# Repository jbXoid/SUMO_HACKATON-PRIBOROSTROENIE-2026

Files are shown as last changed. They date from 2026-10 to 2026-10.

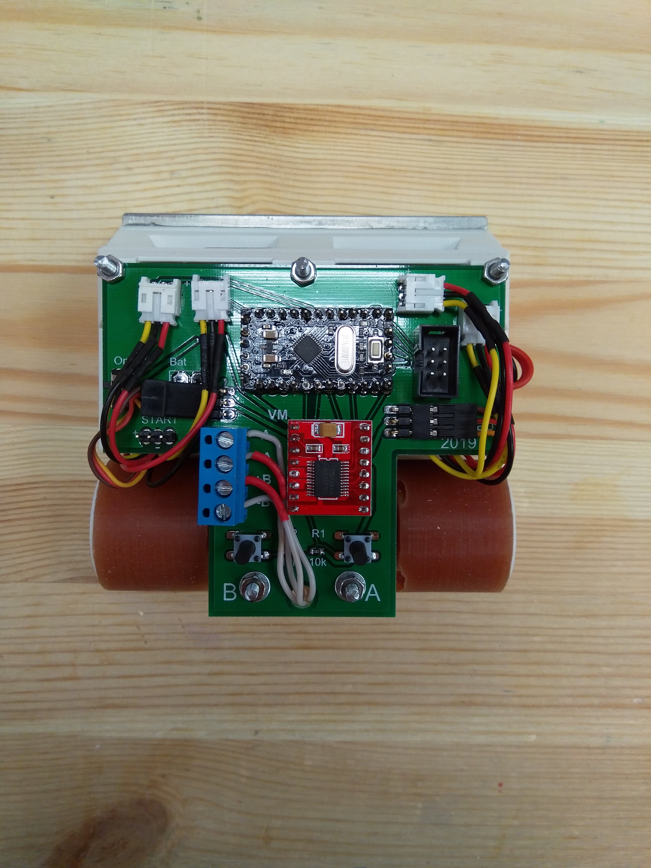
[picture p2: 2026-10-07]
hackaton_files/PHOTO_20191210_112957.jpg

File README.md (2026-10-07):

# Sumo_mini
Programs for ROBOTS Sumo mini

Что доделать:
1. Режим старта Start_Fast;
2. Режим "Периметр";
3. Дефайны выбора ринга (черный или белый);
4. Проработать режим ухода от атаки в бок. Подобрать настройки
5. В процессе ТОРНАДО, если происходит обнаружение цели и переход в АТАКУ, проходит слишком много времени и робот
	успевает проскачить цель. В режиме АТАКА происходит переключение в режим доворота к цели или резкого разворота.
	РЕШЕНИЕ:
	- Попробовать делать переход из "ТОРНАДО" (при обнаружении цели двумя передними датчиками) сразу в "ДОВОРОТ К ЦЕЛИ"
6. Подобрать новые параметры дальности цели в связи с найденной ошибкой поиска среднего арифметического
7. Продумать вопрос работы АЦП через прерывания

Наблюдения:
- Интересный эффект при скоростном старте робота FK35. Если размещать
	неподвижную цель слева или справа от линии входа в ринг, робот
	после входа по прямой развернётся в соответствующую сторону к
	цели.
  Это происходит случайным образом. Проходя мимо цели, в переменной
  ADCH_n сохраняется значение АЦП в момент прохода мимо цели и не
  успевает обновиться новым значением прежде чем выйдет время
  T_START_FAST_IGNORE
	
Улучшения 22.11.2020
---------------------------------------------------------------------
1. Исправлена ошибка настроийки направления вращения моторов. 
	Добавлена строка сброса "PORTD &= ~(1<<IN2|1<<IN3|1<<IN4);"
	в FSM_Go в каждом CASE.
2. Реализован алгоритм определения фронтального контакта
	"ковш в ковш". Добавлен CASE 7 атаки в режиме максимальной
	мощности.
	CASE 1 теперть называется "Выход на цель".
	else if (ADCH_R>=K_FRONT_DIST) //Цель на ковше, но смещена ВПРАВО
				{
				//Подсчёт длительности фронтального контакта.
				Start_GTimer (RRLL_Timer); 
				if(Get_GTimer(RRLL_Timer)>T_FRONT_CONTACT)
					{
					fsm_Go_state=7;
					Stop_GTimer(Motion_Timer);
					Stop_GTimer(RRLL_Timer);
					LED_ON;
					}
3. Исправлен алгоритм в "левом/правом довороте". При потере цели
	сразу переход в режим "Резкий разворот" соответственно текущему
	направлению вращения.
	В режиме "Резкий разворот" удалён кейс отсутствия цели и перехода
	в "Торнадо"
	
Ошибка поиска среднего арифметического
---------------------------------------------------------------------
- Сумма из 5 элементов делилась поразрядным сдвигом вправо на 2.
	Ошибка в том, что так можно делить только на степень двойки.
	Ср.арифм. 8ми элементов нужно сдвинуть на 3 вправо.
- Вместо макс. знач. 153 -> (153*5)>>2, получалось 191

24.07.2021
Среднее арифметическое
---------------------------------------------------------------------
- Данные АЦП сохраняются в массив Buff
- Сохраняется 8 значений каждую мс, затем суммируются
- Поразрядным сдвигом вправо на 3 делается деление на 8
-> Т.к. приходится переключать вход АЦП для каждого канала, нет
	непрерывного потока данных. В таком случае не получится вычислять
	простое скользящее среднее (SMA).
	
25.07.2021
Отключил среднее арифметическое 8ми значений АЦП
---------------------------------------------------------------------
- Значительно улучшилась скорость реакции робота
- Каких-либо импульсов данных АЦП не наблюдается

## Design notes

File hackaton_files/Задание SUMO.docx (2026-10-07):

# SUMO MINI 10X10

Команда, вам предстоит спроектировать боевого робота сумо. Сейчас тут будут накиданы все вводные)

Технические требования к роботу:

- Масса не более - 500 г
- Габаритные размеры в горизонтальной плоскости - (10 х 10) см max
- Вертикальный размер не ограничен
- Робот не должен физически разделяться на части и должен оставаться единым целым
- Робот должен быть полностью автономным
- Шины и другие компоненты робота, контактирующие с рингом, не должны быть способны поднять и удерживать лист A4 плотностью 80 г/м2 более, чем 2 секунды
- Робот не должен быть способным каким-либо образом повредить ринг, других роботов или нанести травмы людям

Что вы получаете на старте проекта:

- Печатную плату
- Электронные компоненты, датчики
- Моторы с редукторами, диски, шины
- Аккумуляторы 18650 3 шт.
- Документацию на ключевые компоненты и электрическую схему платы
- Готовый проект для микроконтроллера ATMega168 на языке Си
- Программатор USBasp
- Ринг
- Массогабаритный макет робота
- 3D модель робота

Что нужно сделать:

- Спаять плату управления роботом
- Собрать аккумуляторную сборку из 3х элементов 18650 подключенных последовательно. Напряжение питания робота 12В
- Скомпилировать проект для микроконтроллера ATMega168 в любой IDE (Microchip Studio или MPLAB для VSCODE)
- Прошить микроконтроллер;
- Внести улучшения в код и рассказать об этом;
- Доработать 3D модель корпуса робота для установки аккумуляторов 18650 и обеспечить достаточно плотную компоновку всех датчиков, электроники и силовой части, чтобы удовлетворить техническим требованиям
- Когда робот будет собран, нужно разместить робота на краю ринга так, чтобы колеса касались белой границы. Когда робот будет включен и инициализирован, он должен самостоятельно обнаружить массогабаритный макет и вытолкнуть его за пределы ринга. При этом робот не должен выпасть из ринга
- На защите проекта вам представиться возможность сразиться с роботом победителем соревнований РОБОФИНИСТ

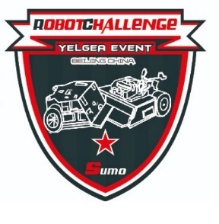
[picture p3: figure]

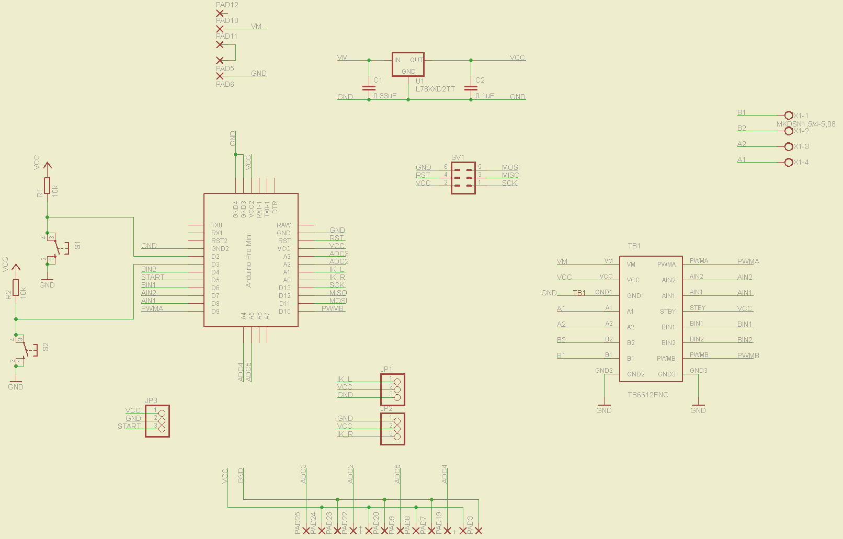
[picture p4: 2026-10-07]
hackaton_files/schematic.png

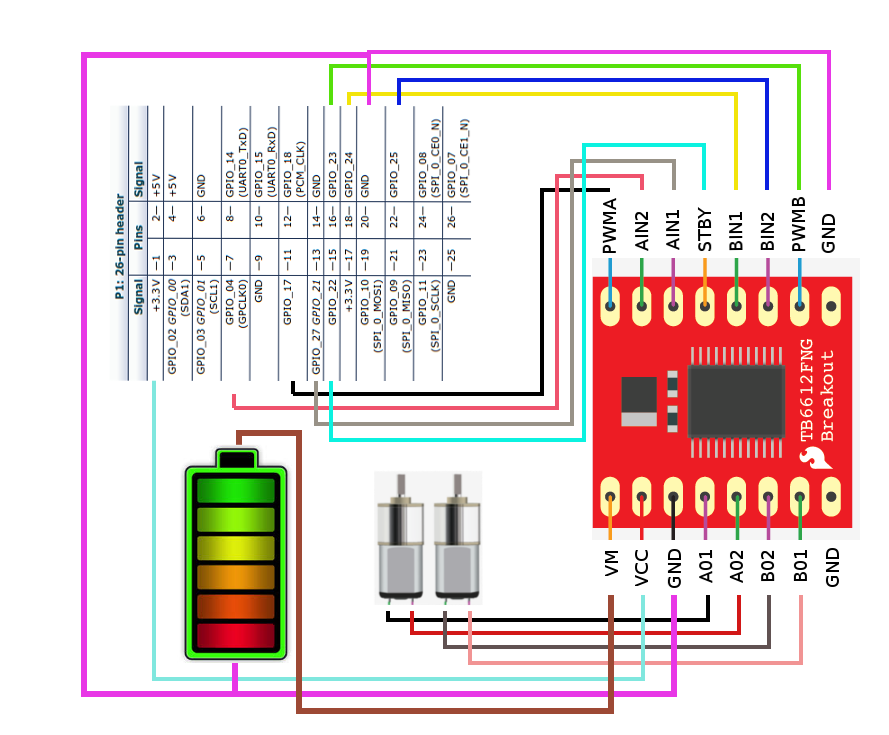
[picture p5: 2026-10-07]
hackaton_files/TB6612FNG.png

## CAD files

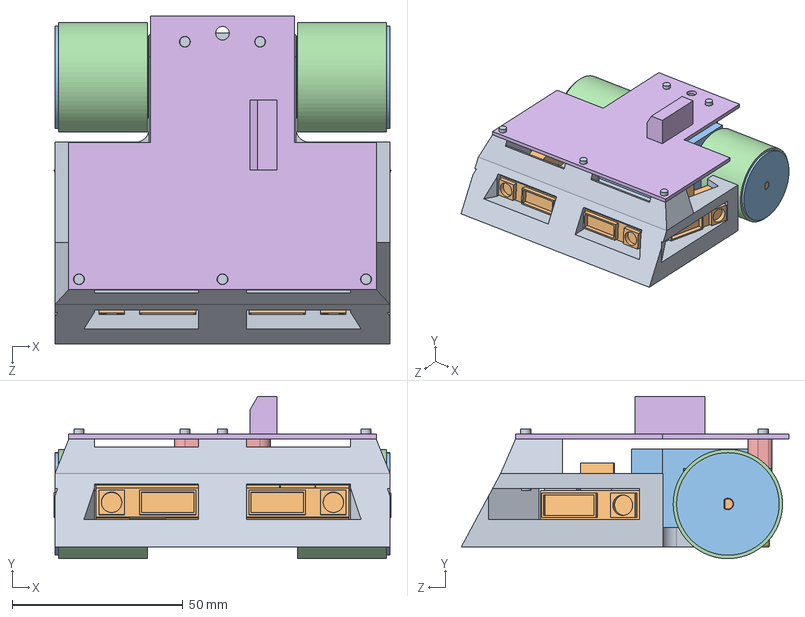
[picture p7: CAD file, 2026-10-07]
hackaton_files/3D model/Sumo_V2.SLDASM
98.6 x 47.5 x 95.9 mm
Рама_v1.2
Двигатель x 2
Диск_d24 x 2
Покрышка x 2
Крышка
Board
Винт_М3_20_DIN912 x 4
Гайка_М3 x 4
Шпилька_М3 x 5
SHARP 2Y0A21 F81 x 4
Груз_255г

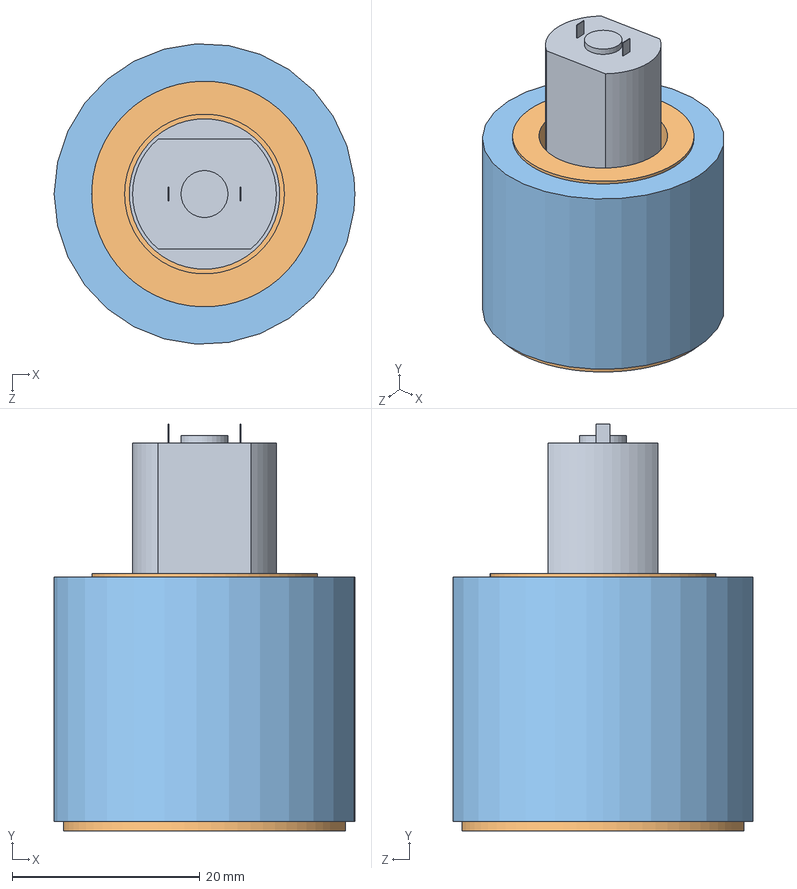
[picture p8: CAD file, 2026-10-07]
hackaton_files/3D model/Привод.SLDASM
32.0 x 43.3 x 32.0 mm
Двигатель
Диск_d24
Покрышка

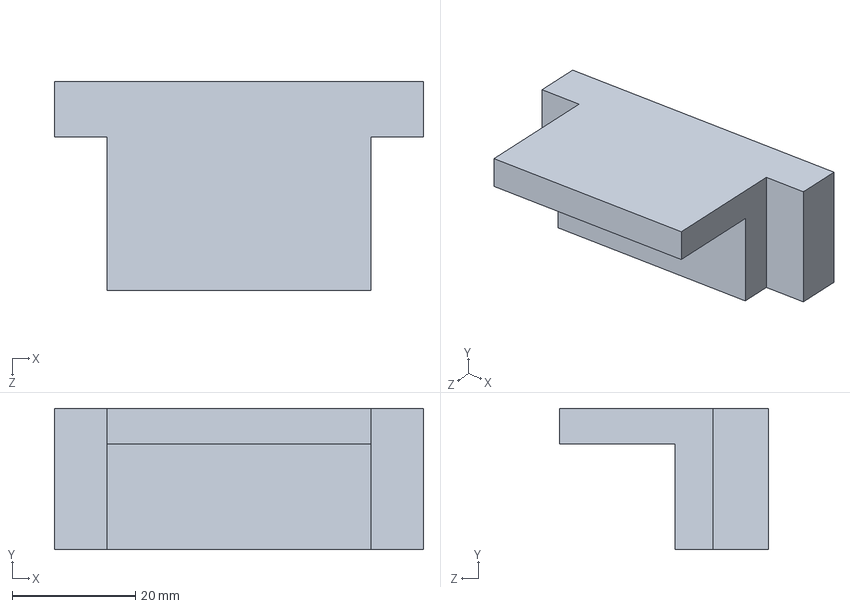
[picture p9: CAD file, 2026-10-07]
hackaton_files/3D model/Груз_255г.SLDPRT
60.0 x 23.0 x 34.0 mm

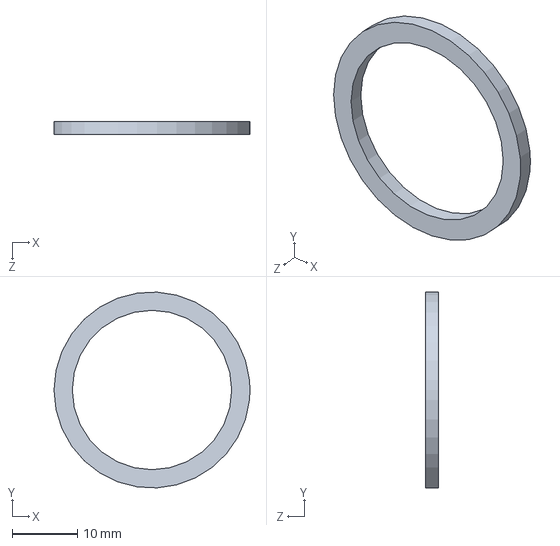
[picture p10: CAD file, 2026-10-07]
hackaton_files/3D model/Обод.SLDPRT
30.0 x 30.0 x 2.00 mm

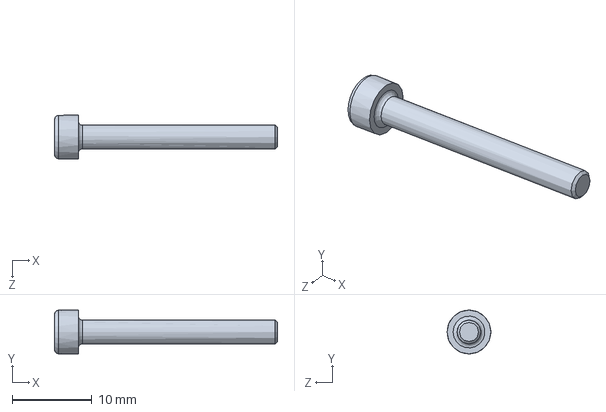
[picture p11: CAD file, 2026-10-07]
hackaton_files/3D model/Винт_М3_25_DIN912.SLDPRT
28.0 x 5.50 x 5.50 mm

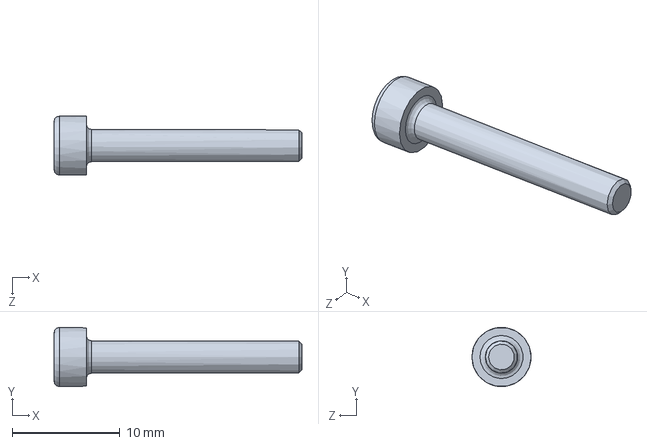
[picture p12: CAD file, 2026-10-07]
hackaton_files/3D model/Винт_М3_20_DIN912.SLDPRT
23.0 x 5.49 x 5.50 mm

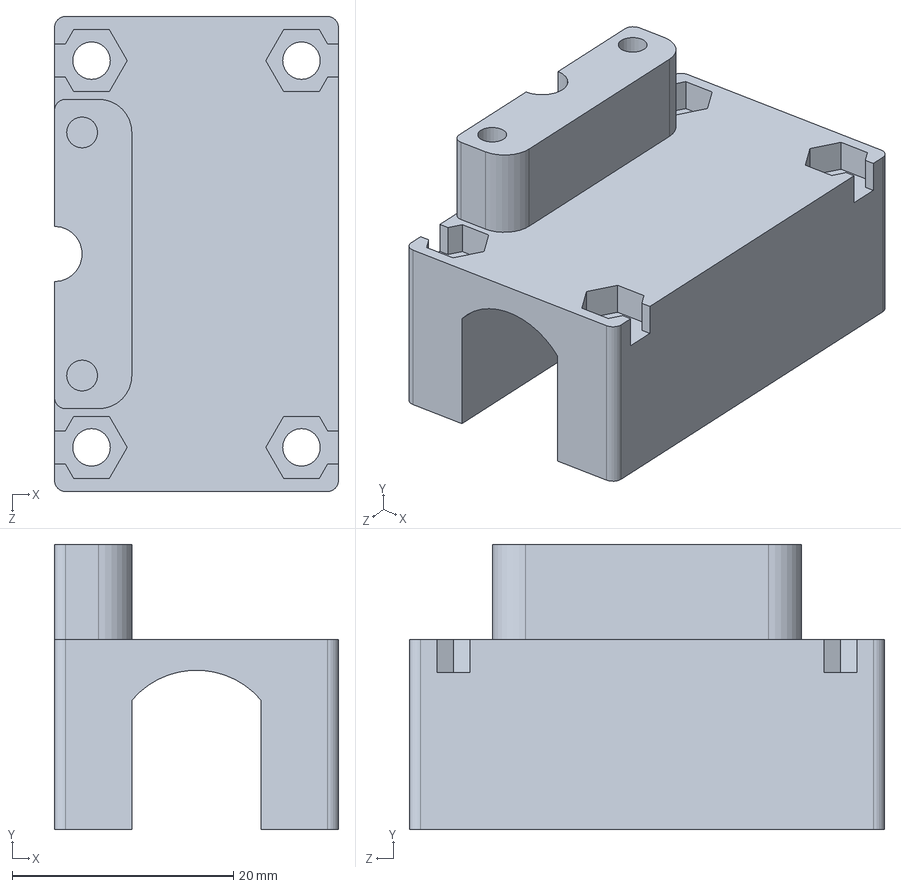
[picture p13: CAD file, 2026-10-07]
hackaton_files/3D model/Крышка.SLDPRT
25.7 x 25.8 x 43.0 mm

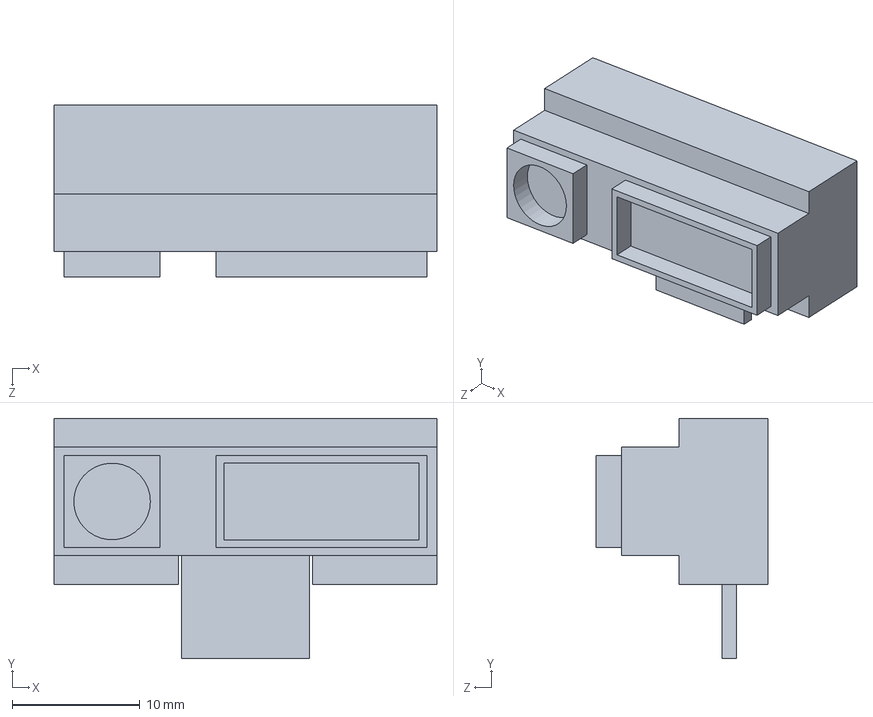
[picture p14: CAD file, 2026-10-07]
hackaton_files/3D model/SHARP 2Y0A21 F81.SLDPRT
30.0 x 18.8 x 13.5 mm

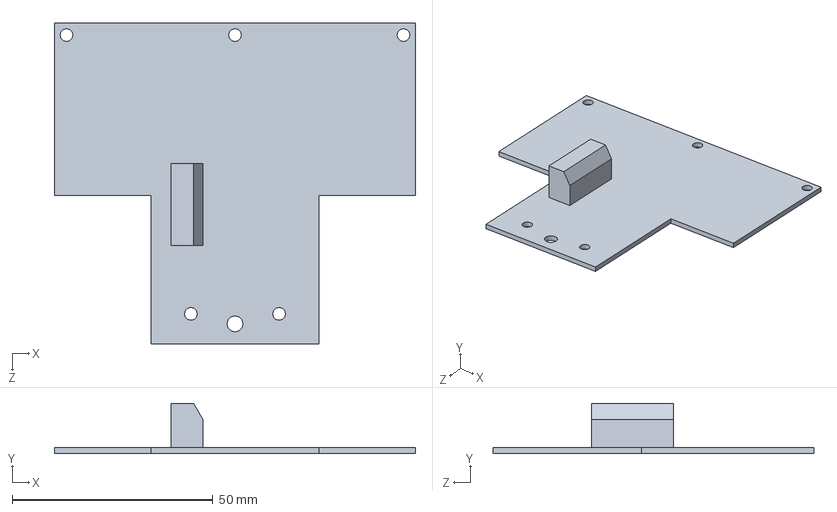
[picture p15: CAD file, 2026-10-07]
hackaton_files/3D model/Board.SLDPRT
90.0 x 12.5 x 80.0 mm

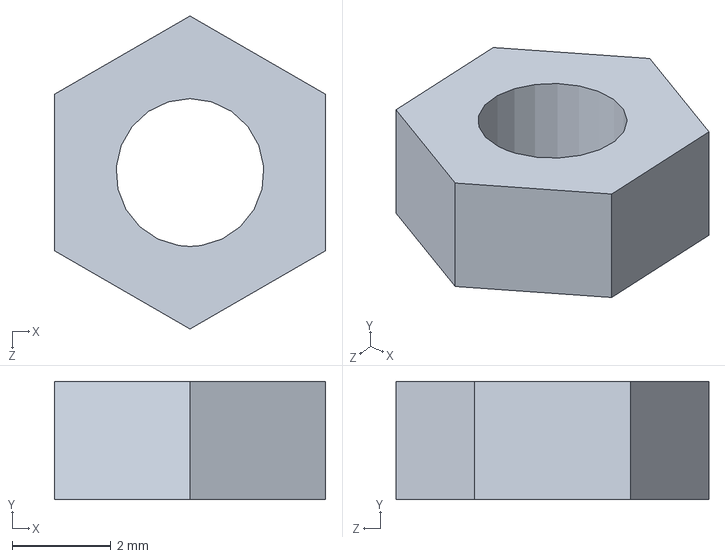
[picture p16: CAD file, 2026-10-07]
hackaton_files/3D model/Гайка_М3.SLDPRT
5.50 x 2.40 x 6.35 mm

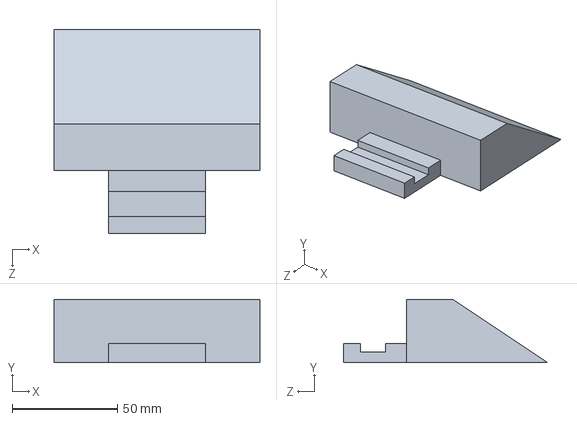
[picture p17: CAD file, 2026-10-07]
hackaton_files/3D model/Рама.SLDPRT
98.0 x 30.0 x 97.0 mm

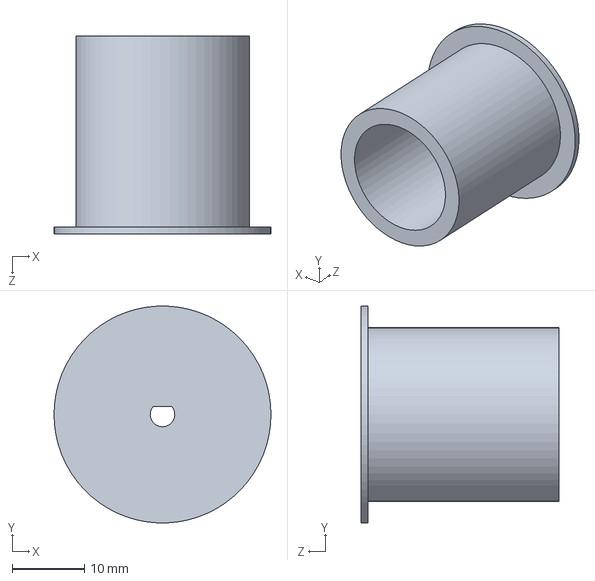
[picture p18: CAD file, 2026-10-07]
hackaton_files/3D model/Диск_d24.SLDPRT
30.0 x 30.0 x 27.4 mm

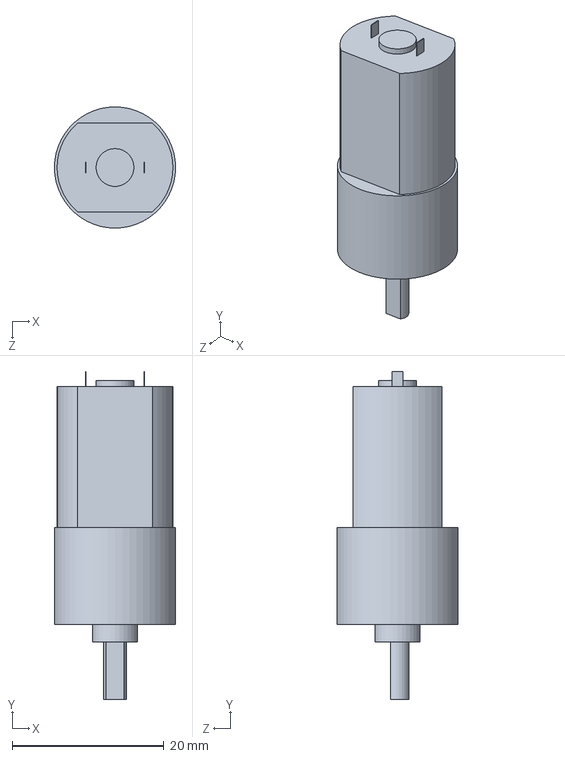
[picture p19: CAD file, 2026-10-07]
hackaton_files/3D model/Двигатель.SLDPRT
16.0 x 43.3 x 16.0 mm

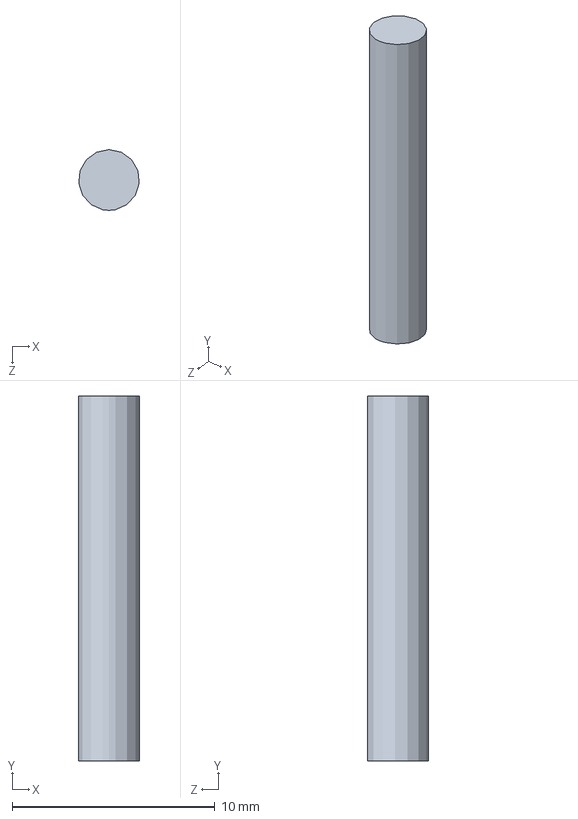
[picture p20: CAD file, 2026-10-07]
hackaton_files/3D model/Шпилька_М3.SLDPRT
2.98 x 18.0 x 3.00 mm

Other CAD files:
hackaton_files/3D model/Arduino_Pro_mini.SLDPRT
hackaton_files/3D model/Покрышка.SLDPRT
hackaton_files/3D model/Рама_v1.2.SLDPRT

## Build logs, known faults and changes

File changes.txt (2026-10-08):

0. MADE MAKEFILE FOR BUILDING

1. FIXING SYNTAX ERRORS AND BUILDING/FLASHING FIRST TIME

1.1. Deleted ' #include "EEPROM" ' (We don't use it)

1.2. Made tabs in main.c to make code more readable

1.3. Excluded DC_motor_driver.c from building (will be included after fix)

FIRST BUILDED

- Fixed Makefile

FIRST FLASHED

2. MAKING DIAGNOSTICS CODE

2.1. Setting up UART Debug transmission

2.1. Copied needed files

2.2.1. Made send_text_usart function

2.2.2 Made test code

2.2. Made diagnostics code

2.2.1. Made SHARP sensors diagnostics

2.2.2. Made motors diagnostics

2.2.3. Made line sensors diagnostics

2.3. DC MOTOR DRIVER

2.3.1. Have done driver

2.3.2. Changed every motor controlling to driver functoin

2.4. FIXING LOGIC

2.4.1 Fixed edge checking while attacking

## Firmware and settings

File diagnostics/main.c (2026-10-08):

#include "main.h"

void init_port(void);

typedef enum {
    NONE, SHARP_TEST, MOTOR_TEST, LINE_SENSOR_TEST
} Mode; 

int main (void)	
{
    
    init_port();
    init_USART();
    Init_GTimer();
    init_timer1();

    InitFSM_SHARP_ADC();
    sei();

    Mode diag_mode = NONE;

    const char begin_text[] = "DIAGNOSTICS. PRESS A TO SWITCH THROUGH MODES: SHARP_TEST, MOTOR_TEST, LINE_SENSOR\r\n";
    send_text_uart( (unsigned char *)begin_text, sizeof(begin_text) - 1 );

    uint8_t Prev_Pin_D = PIND;
    uint8_t Pin_D = PIND;


    bool motor_direction = 0;
    bool motor_speed_rising = 0;

    while(1) {

        // Checking buttons
        Pin_D = PIND;
        if ( ( Prev_Pin_D & BUTTON_A ) && !( Pin_D & BUTTON_A ) ) {
            
            diag_mode = (Mode)((diag_mode + 1) % 4);

            char press_text[23];
            int len = snprintf(press_text, sizeof(press_text),
                                "SWITCHING MODE TO %d\r\n",
                                (int)diag_mode
                    );

            send_text_uart( (unsigned char *)press_text, (uint16_t)len );


            PORTB &= ~(1<<0);
            PORTD &= ~(1<<7);

            PORTD &= ~(1<<4);
            PORTD &= ~(1<<6);
            
            OCR1A = 0;
            OCR1B = 0;

            Start_GTimer(10);

        }
        Prev_Pin_D = Pin_D;

        // Modes
        switch ( diag_mode ) {
            
            default: {
                break;
            }

            case SHARP_TEST: 
            
                if ( Get_GTimer(10) >= 500 ) {
                        
                    // Processing SHARP
                    ProcessFSM_SHARP_ADC();

                    char debug_text[100];
                    int len = snprintf(debug_text, sizeof(debug_text),
                                       "LEFT: %03u\r\n"
                                       "FORWARD LEFT: %03u\r\n"
                                       "FORWARD RIGHT: %03u\r\n"
                                       "RIGHT: %03u\r\n"
                                       "\r\n",
                                       (unsigned int)ADCH_LL,
                                       (unsigned int)ADCH_L,
                                       (unsigned int)ADCH_R,
                                       (unsigned int)ADCH_RR);

                    if (len > 0 && (size_t)len < sizeof debug_text) {
                        send_text_uart((unsigned char *)debug_text, (uint16_t)len);
                    }
                   
                    Stop_GTimer(10);
                    Start_GTimer(10);
                }

                break;

            case MOTOR_TEST:
                
                if (Get_GTimer(10) >= 10 ) {



                    if( motor_speed_rising ) {

                        if ( OCR1A == 255 && OCR1B == 255) {
                            
                            motor_speed_rising = 0;

                        }

                    }

                    else {

                        if( OCR1A == 0 && OCR1B == 0 ) {

                            motor_speed_rising = 1;
                            motor_direction = !motor_direction;

                        }

                    }

                    
                    switch( motor_speed_rising ) {

                        case 0:

                            OCR1A --;
                            OCR1B --;

                            break;

                        case 1:

                            OCR1A ++;
                            OCR1B ++;

                            break;

                    }


                    switch( motor_direction ) {

                        case 0:

                            PORTD |= (1<<7);
                            PORTB &= ~(1<<0);

                            PORTD |= (1<<6);
                            PORTD &= ~(1<<4);

                            break;

                        case 1: 
                            
                            PORTD &= ~(1<<7);
                            PORTB |= (1<<0);

                            PORTD |= (1<<4);
                            PORTD &= ~(1<<6);

                            break;

                    }            


                    Stop_GTimer(10);
                    Start_GTimer(10);

                }
                break;

            case LINE_SENSOR_TEST:

                if ( Get_GTimer(10) >= 500 ) {
                    
                    char debug_text[100];

                    int len = snprintf( debug_text, sizeof(debug_text),
                            "FIRST SENSOR: %d\r\n"
                            "SECOND SENSOR: %d\r\n"
                            "\r\n",
                            (PINC & _BV(PC0)) != 0,
                            (PINC & _BV(PC1)) != 0
                            );

                    if (len > 0 && (size_t)len < sizeof debug_text) {
                        send_text_uart((unsigned char *)debug_text, (uint16_t)len);
                    }
                   
                    Stop_GTimer(10);
                    Start_GTimer(10);
                }

        }

    }
}

void init_port(void)
{
	DDRB |= (1<<ENA|1<<ENB|1<<IN1);	//Управление двигателями
	DDRD |= (1<<IN2|1<<IN3|1<<IN4|0<<BUTTOM_L|0<<BUTTOM_R); //Управление двигателями - порты на выход; кнопки PD3,PD2 - порты на вход.
	PORTD |= (1<<BUTTOM_L|1<<BUTTOM_R); //Кнопки PD3,PD2 - порты в режиме PullUp с подтяжкой к 1.

	DDRC |= (0<<DDC5|0<<DDC4|0<<DDC3|0<<DDC2|0<<DDC1|0<<DDC0); //Входы (инфракрасные датчики и датчик расстояния) в режиме Hi-Z

	ADC_INIT_R; //инициализация АЦП. Читаем сигнал с порта PC5 (правый датчик). Данные берем с ADCH. Опорное-5V(255). Сигнал до 3V(153).
	ADC_ON; //запуск АЦП.
}

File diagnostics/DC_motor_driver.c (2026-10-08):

#include "main.h"

void DC_Motors (enum Action action, uint8_t speed)
{
cli();
    
    OCR1A = speed;
    OCR1B = speed;

	switch(action) {

        case FORWARD:

            PORTB |= (1<<0);
            PORTD &= ~(1<<7);

            PORTD |= (1<<4);
            PORTD &= ~(1<<6);


            break;

        case BACK:

            PORTB &= ~(1<<0);
            PORTD |= (1<<7);

            PORTD &= ~(1<<4);
            PORTD |= (1<<6);

            break;

        case LEFT:

            PORTB &= ~(1<<0);
            PORTD &= ~(1<<7);

            PORTD |= (1<<4);
            PORTD &= ~(1<<6);

            break;
 
        case RIGHT:

            PORTB |= (1<<0);
            PORTD &= ~(1<<7);

            PORTD &= ~(1<<4);
            PORTD &= ~(1<<6);

            break;

        case TORNADO_LEFT:

            PORTB &= ~(1<<0);
            PORTD |= (1<<7);

            PORTD |= (1<<4);
            PORTD &= ~(1<<6);
            
            break;
        
        case TORNADO_RIGHT:

            PORTB |= (1<<0);
            PORTD &= ~(1<<7);

            PORTD &= ~(1<<4);
            PORTD |= (1<<6);
            
            break;


        case STOP:

            PORTB &= ~(1<<0);
            PORTD &= ~(1<<7);

            PORTD &= ~(1<<4);
            PORTD &= ~(1<<6);
            
            break;

    }

    OCR1A = speed;
    OCR1B = speed;
sei();	
}
//В рамках организации программы через автоматы FSM не представляется возможным создать функцию DC_Motors с возможностью паузы на момент реверса.

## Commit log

2026-10-07 Fixed makefile, made diagnostics code
    [Arduino_Pro_mini.SLDPRT, Board.SLDPRT, SHARP 2Y0A21 F81.SLDPRT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]
2026-10-08 Fixed edge checking while attacking, fixed dc_motor_driver, updated changes.txt
    [DC_motor_driver.c, FSM_Go.c, main.c]
2026-10-08 Fixed FSM_Tornado, fixed diagnostics
    [FSM_Go.c, FSM_Tornado.c, main.c]
2026-10-08 Added tracking target and fixed diagnostics
    [DC_motor_driver.c, FSM_Go.c, FSM_Go.h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]
